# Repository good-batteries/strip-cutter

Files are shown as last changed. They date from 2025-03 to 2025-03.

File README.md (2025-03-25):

# Simple Strip Cutter

## Description

[Українська версія](README_ua.md)

Instructions on assembling a simple strip cutter used in battery manufacturing. The device also has the capability to weld a second layer of strip for welding copper using "sandwich" technology. Included are 3D print files and code for Arduino Nano.

- [Video introduction](https://www.youtube.com/watch?v=2g4eOFBQs-M)
- [Jig mentioned in the previous video](https://youtu.be/SqSB7JrVHbk)

Demo Gif

## Table of Contents

- [Arduino Nano Flashing](#arduino-nano-flashing)
- [List of Parts](#list-of-parts)
- [Electrical Schematic](#electrical-schematic)
- [TODO](#todo)

## Arduino Nano Flashing

- Install libraries using Arduino's IDE Library Manager:
  - Search for and install **AccelStepper**
  - Search for and install **VL53L0X_mod**
- If the welder functionality is not needed:
  - Change `bool needWelder = true;` to `bool needWelder = false;` in the code.
- To test modules separately, locate `// UNCOMMENT NEEDED TEST` in the code and follow the instructions provided.

## List of Parts

- **CNC Shield for Arduino Uno**  
  [https://vi.aliexpress.com/item/1005002807506440.html](https://vi.aliexpress.com/item/1005002807506440.html)
- **CNC Shield for Arduino Nano**  
  [https://vi.aliexpress.com/item/32834755847.html](https://vi.aliexpress.com/item/32834755847.html)
- **Step Motor NEMA17 JK42HS40**  
  [https://arduino.ua/prod2962-shagovii-dvigatel-nema17-jk42hs40-1704-13a-b](https://arduino.ua/prod2962-shagovii-dvigatel-nema17-jk42hs40-1704-13a-b)  
  [https://evse.com.ua/shagovyj-dvigatel-nema17-17a-17hs4401-3d-printer](https://evse.com.ua/shagovyj-dvigatel-nema17-17a-17hs4401-3d-printer)
- **Welding Handle**  
  [https://vi.aliexpress.com/item/1005006570618453.html](https://vi.aliexpress.com/item/1005006570618453.html)
- **Scissors JTC 3422A**  
  [https://jtc.com.ua/instrument-zagalnogo-priznachennya/instrument-slyusarnij/nozhici-bagatofunkcionalni/](https://jtc.com.ua/instrument-zagalnogo-priznachennya/instrument-slyusarnij/nozhici-bagatofunkcionalni/)
- **Relay 5V 10A Low Level**  
  [https://arduino.ua/prod1706-modyl-rele-5v-10a-nizkogo-yrovnya-low-level](https://arduino.ua/prod1706-modyl-rele-5v-10a-nizkogo-yrovnya-low-level)
- **Step Motor Driver StepStick A4988**  
  [https://arduino.ua/prod965-draiver-shagovogo-dvigatelya-stepstick-a4988](https://arduino.ua/prod965-draiver-shagovogo-dvigatelya-stepstick-a4988)
- **Laser Distance Sensor GY-530 on VL53L0X**  
  [https://arduino.ua/prod2144-lazernii-datchik-rasstoyaniya-gy-530-na-vl53l0x](https://arduino.ua/prod2144-lazernii-datchik-rasstoyaniya-gy-530-na-vl53l0x)
- **Strip**  
  [https://vi.aliexpress.com/item/1005008182375950.html](https://vi.aliexpress.com/item/1005008182375950.html)
- **Button**  
  [https://arduino.ua/prod3756-knopka-pbs-33b-bez-fiksacii-off-on-krasnaya](https://arduino.ua/prod3756-knopka-pbs-33b-bez-fiksacii-off-on-krasnaya)  
  [https://arduino.ua/prod3528-knopka-avariinoi-ostanovki](https://arduino.ua/prod3528-knopka-avariinoi-ostanovki)
- **Breadboard**  
  [https://arduino.ua/prod361-maketnaya-plata-mb-102-830-otverstii](https://arduino.ua/prod361-maketnaya-plata-mb-102-830-otverstii)
- **Breadboard for Soldering**  
  [https://arduino.ua/prod4130-mednaya-maketnaya-plata-diy-stripboard-iz-getinaksa-133x48-mm](https://arduino.ua/prod4130-mednaya-maketnaya-plata-diy-stripboard-iz-getinaksa-133x48-mm)
- **Arduino Nano**  
  [https://arduino.ua/prod6510-arduino-nano-v3-0-avr-atmega328p-type-c](https://arduino.ua/prod6510-arduino-nano-v3-0-avr-atmega328p-type-c)
- **Wires**  
  [https://arduino.ua/prod195-nabor-peremichek-dlya-arduino-65-sht](https://arduino.ua/prod195-nabor-peremichek-dlya-arduino-65-sht)
- **Voltage Regulator LM7805 TO-220**  
  [https://arduino.ua/prod1844-stabilizator-napryajeniya-lm7805-to-220](https://arduino.ua/prod1844-stabilizator-napryajeniya-lm7805-to-220)
- **Capacitor**  
  [https://arduino.ua/prod6477-kondensator-elektrolitichnii-jccon-47mkf-25v-lowesr](https://arduino.ua/prod6477-kondensator-elektrolitichnii-jccon-47mkf-25v-lowesr)
- **Resistors**  
  [https://arduino.ua/prod409-nabor-rezistorov-0-25w-600-sht](https://arduino.ua/prod409-nabor-rezistorov-0-25w-600-sht)
- **Servo SG90**  
  [https://arduino.ua/prod416-servoprivod-sg90-2kg](https://arduino.ua/prod416-servoprivod-sg90-2kg)
- **Plug 5.5x2.5mm**  
  [https://arduino.ua/prod1380-shteker-2-5-h-5-5-mm-papa-1-sht](https://arduino.ua/prod1380-shteker-2-5-h-5-5-mm-papa-1-sht)
- **Socket DC 5.5/2.5mm**  
  [https://arduino.ua/prod3909-gnezdo-pitaniya-dc-5-52-5mm-s-klemmnoi-kolodkoi-pod-vint](https://arduino.ua/prod3909-gnezdo-pitaniya-dc-5-52-5mm-s-klemmnoi-kolodkoi-pod-vint)
- **Power Supply 12V**  
  [https://evse.com.ua/blok-pitaniya-setevoj-adapter-12v-6a-55x21mm-55x25mm-kabel](https://evse.com.ua/blok-pitaniya-setevoj-adapter-12v-6a-55x21mm-55x25mm-kabel)

## Electrical Schematic

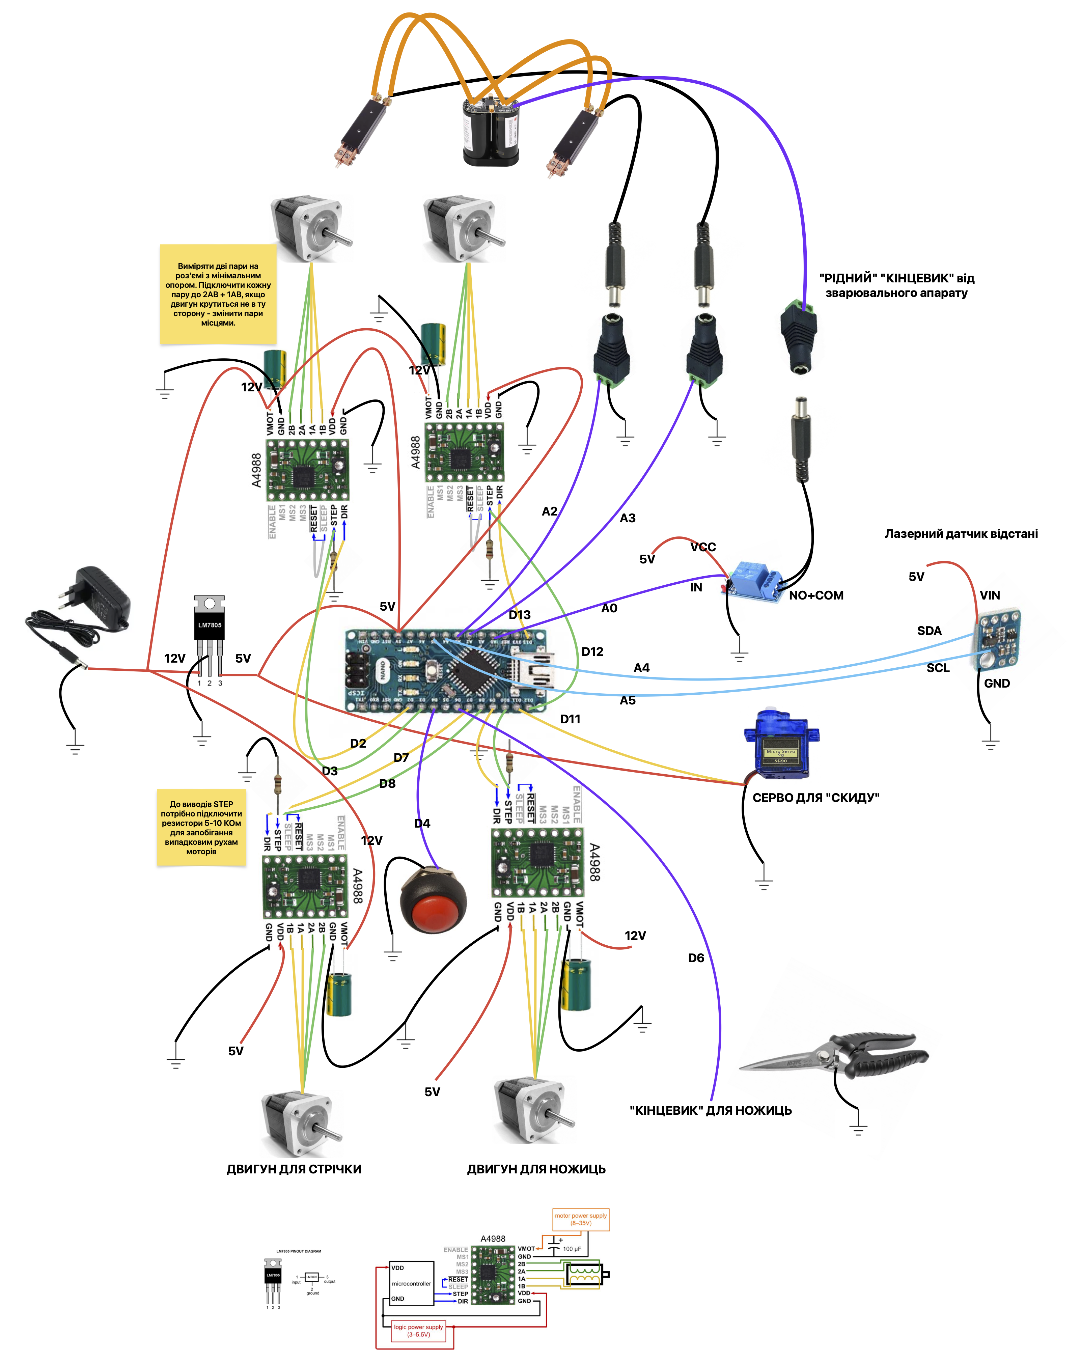
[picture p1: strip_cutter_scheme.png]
Strip Cutter Schematic


## TODO

- Clean up the code.
- Improve the electrical schematic.
- Redesign scissors motor holder - it is ugly.

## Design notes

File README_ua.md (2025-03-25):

# Простий Різак для Стрічки

## Опис

Інструкція зі складання простого різака для стрічки, який використовується у виробництві батарей. Пристрій також має можливість приварювати другий шар стрічки для зварювання міді за технологією "сендвіч". У комплекті є 3D-файли для друку та код для Arduino Nano.

- [Відео-інструкція](https://www.youtube.com/watch?v=2g4eOFBQs-M)
- [Кондуктор, згаданий у відео](https://youtu.be/SqSB7JrVHbk)

Demo Gif

## Зміст

- [Прошивка Arduino Nano](#прошивка-arduino-nano)
- [Список деталей](#список-деталей)
- [Електрична схема](#електрична-схема)
- [TODO](#todo)

## Прошивка Arduino Nano

- Встановіть бібліотеки за допомогою Менеджера бібліотек Arduino IDE:
  - Знайдіть та встановіть **AccelStepper**.
  - Знайдіть та встановіть **VL53L0X_mod**.
- Якщо функція зварювання не потрібна:
  - Змініть `bool needWelder = true;` на `bool needWelder = false;` у коді.
- Для тестування модулів окремо знайдіть `// UNCOMMENT NEEDED TEST` у коді та дотримуйтеся інструкцій.

## Список деталей

- **CNC Shield для Arduino Uno**  
  [https://vi.aliexpress.com/item/1005002807506440.html](https://vi.aliexpress.com/item/1005002807506440.html)
- **CNC Shield для Arduino Nano**  
  [https://vi.aliexpress.com/item/32834755847.html](https://vi.aliexpress.com/item/32834755847.html)
- **Кроковий двигун NEMA17 JK42HS40**  
  [https://arduino.ua/prod2962-shagovii-dvigatel-nema17-jk42hs40-1704-13a-b](https://arduino.ua/prod2962-shagovii-dvigatel-nema17-jk42hs40-1704-13a-b)  
  [https://evse.com.ua/shagovyj-dvigatel-nema17-17a-17hs4401-3d-printer](https://evse.com.ua/shagovyj-dvigatel-nema17-17a-17hs4401-3d-printer)
- **Зварювальний тримач**  
  [https://vi.aliexpress.com/item/1005006570618453.html](https://vi.aliexpress.com/item/1005006570618453.html)
- **Ножиці JTC 3422A**  
  [https://jtc.com.ua/instrument-zagalnogo-priznachennya/instrument-slyusarnij/nozhici-bagatofunkcionalni/](https://jtc.com.ua/instrument-zagalnogo-priznachennya/instrument-slyusarnij/nozhici-bagatofunkcionalni/)
- **Реле 5V 10A (низький рівень)**  
  [https://arduino.ua/prod1706-modyl-rele-5v-10a-nizkogo-yrovnya-low-level](https://arduino.ua/prod1706-modyl-rele-5v-10a-nizkogo-yrovnya-low-level)
- **Драйвер крокового двигуна StepStick A4988**  
  [https://arduino.ua/prod965-draiver-shagovogo-dvigatelya-stepstick-a4988](https://arduino.ua/prod965-draiver-shagovogo-dvigatelya-stepstick-a4988)
- **Лазерний датчик відстані GY-530 на VL53L0X**  
  [https://arduino.ua/prod2144-lazernii-datchik-rasstoyaniya-gy-530-na-vl53l0x](https://arduino.ua/prod2144-lazernii-datchik-rasstoyaniya-gy-530-na-vl53l0x)
- **Стрічка**  
  [https://vi.aliexpress.com/item/1005008182375950.html](https://vi.aliexpress.com/item/1005008182375950.html)
- **Кнопка**  
  [https://arduino.ua/prod3756-knopka-pbs-33b-bez-fiksacii-off-on-krasnaya](https://arduino.ua/prod3756-knopka-pbs-33b-bez-fiksacii-off-on-krasnaya)  
  [https://arduino.ua/prod3528-knopka-avariinoi-ostanovki](https://arduino.ua/prod3528-knopka-avariinoi-ostanovki)
- **Макетна плата**  
  [https://arduino.ua/prod361-maketnaya-plata-mb-102-830-otverstii](https://arduino.ua/prod361-maketnaya-plata-mb-102-830-otverstii)
- **Перфорована плата для паяння**  
  [https://arduino.ua/prod4130-mednaya-maketnaya-plata-diy-stripboard-iz-getinaksa-133x48-mm](https://arduino.ua/prod4130-mednaya-maketnaya-plata-diy-stripboard-iz-getinaksa-133x48-mm)
- **Arduino Nano**  
  [https://arduino.ua/prod6510-arduino-nano-v3-0-avr-atmega328p-type-c](https://arduino.ua/prod6510-arduino-nano-v3-0-avr-atmega328p-type-c)
- **Дроти**  
  [https://arduino.ua/prod195-nabor-peremichek-dlya-arduino-65-sht](https://arduino.ua/prod195-nabor-peremichek-dlya-arduino-65-sht)
- **Стабілізатор напруги LM7805 TO-220**  
  [https://arduino.ua/prod1844-stabilizator-napryajeniya-lm7805-to-220](https://arduino.ua/prod1844-stabilizator-napryajeniya-lm7805-to-220)
- **Конденсатор**  
  [https://arduino.ua/prod6477-kondensator-elektrolitichnii-jccon-47mkf-25v-lowesr](https://arduino.ua/prod6477-kondensator-elektrolitichnii-jccon-47mkf-25v-lowesr)
- **Резистори**  
  [https://arduino.ua/prod409-nabor-rezistorov-0-25w-600-sht](https://arduino.ua/prod409-nabor-rezistorov-0-25w-600-sht)
- **Серво SG90**  
  [https://arduino.ua/prod416-servoprivod-sg90-2kg](https://arduino.ua/prod416-servoprivod-sg90-2kg)

## Електрична схема

Схема різака стрічки

## TODO

- Оптимізувати код.
- Покращити електричну схему.
- Переробити дизайн для двигуна ножиць, він зараз уродливий.

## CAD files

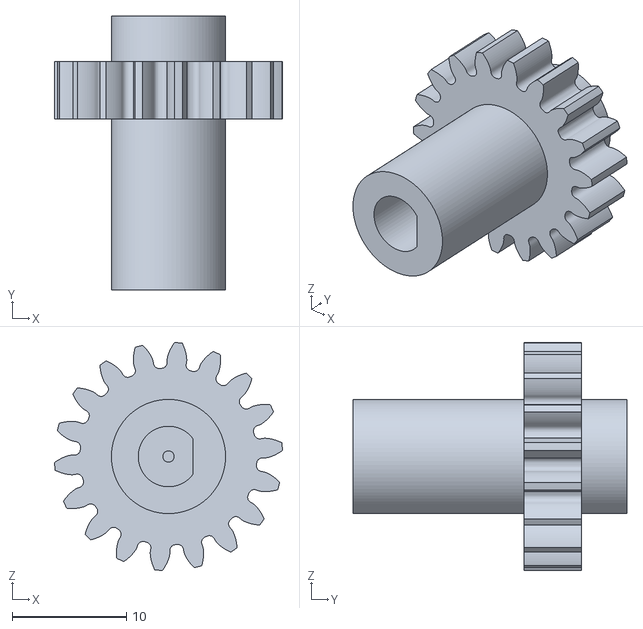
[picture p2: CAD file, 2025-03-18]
3D Print/Welder Mover/MainGear.stl
20.0 x 24.0 x 20.0

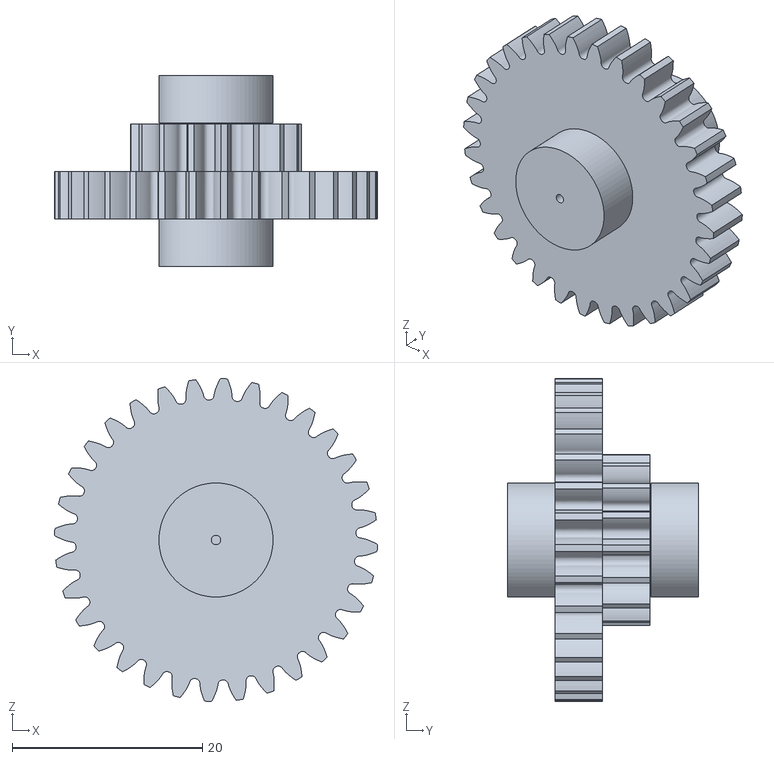
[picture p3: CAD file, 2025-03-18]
3D Print/Strip Mover/MainGears.stl
34.0 x 20.1 x 34.0

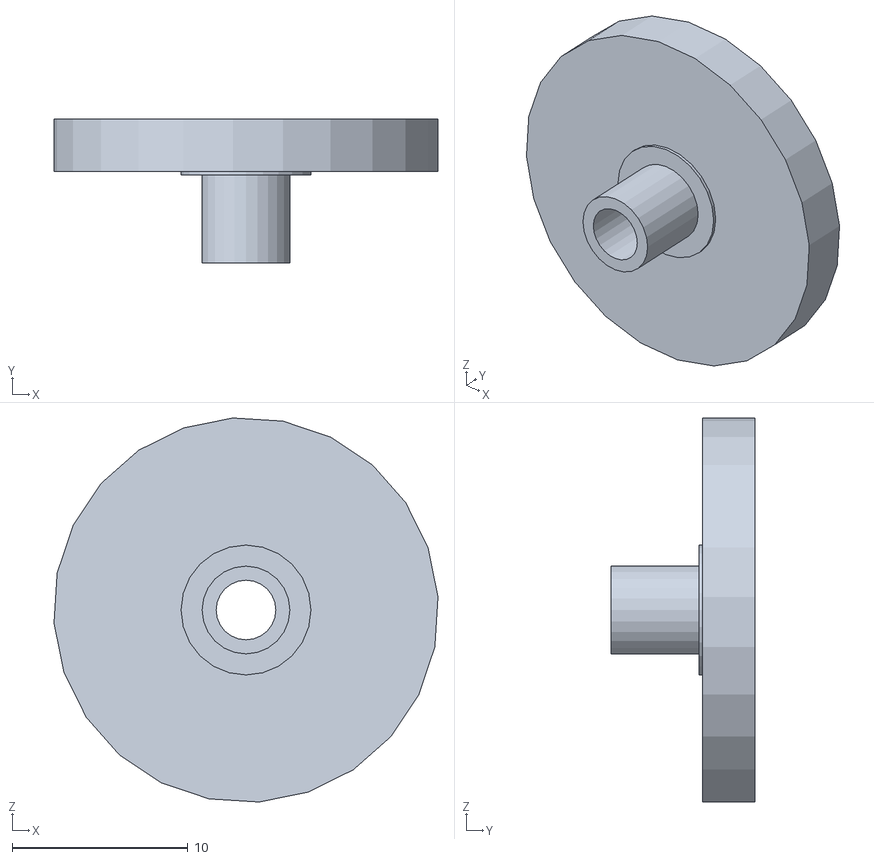
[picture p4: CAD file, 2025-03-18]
3D Print/Scissors Mover/Bearing_Holder.stl
21.9 x 8.20 x 21.9

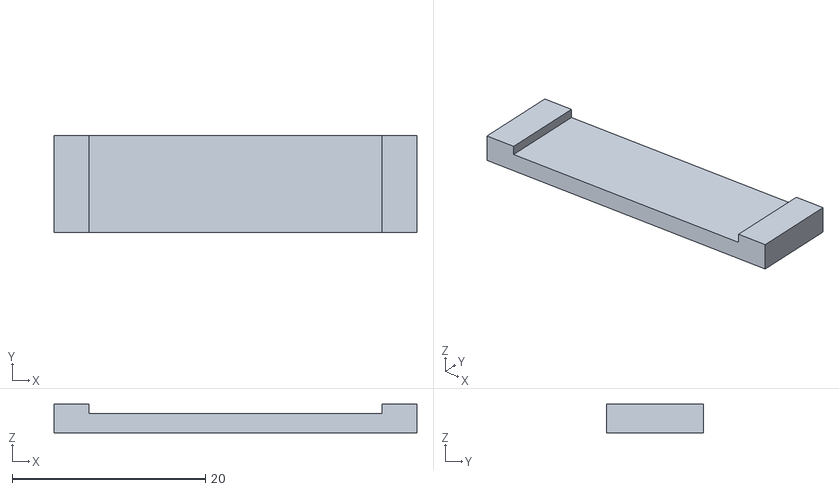
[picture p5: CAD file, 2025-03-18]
3D Print/Strip Guide/Double Sandwich/cap1.stl
37.6 x 10.0 x 3.00

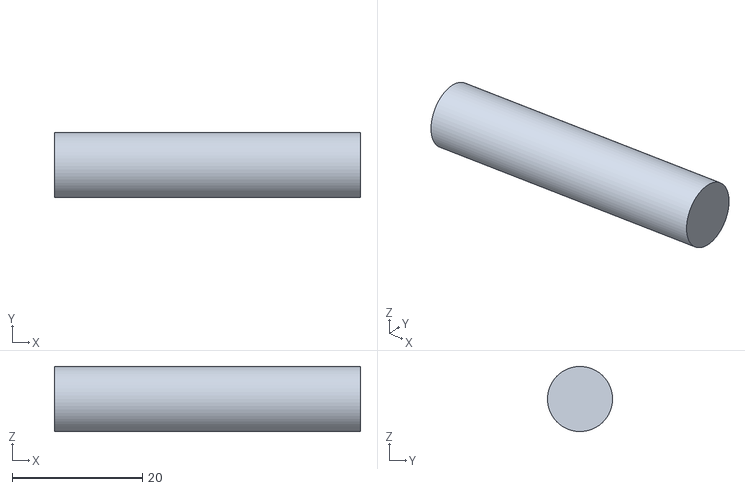
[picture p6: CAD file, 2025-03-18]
3D Print/Strip Guide/Pin.stl
47.0 x 9.99 x 10.00

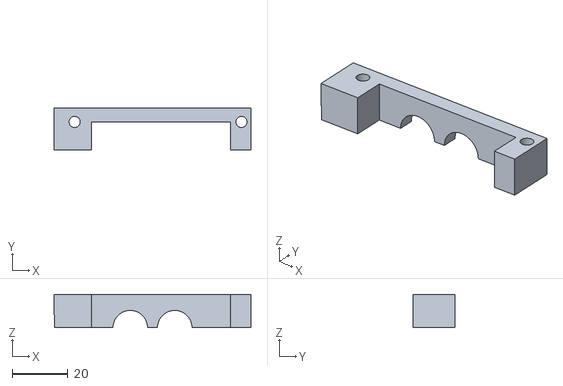
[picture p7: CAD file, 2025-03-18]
3D Print/Strip Mover/Frame1_Top.stl
70.9 x 15.1 x 12.0

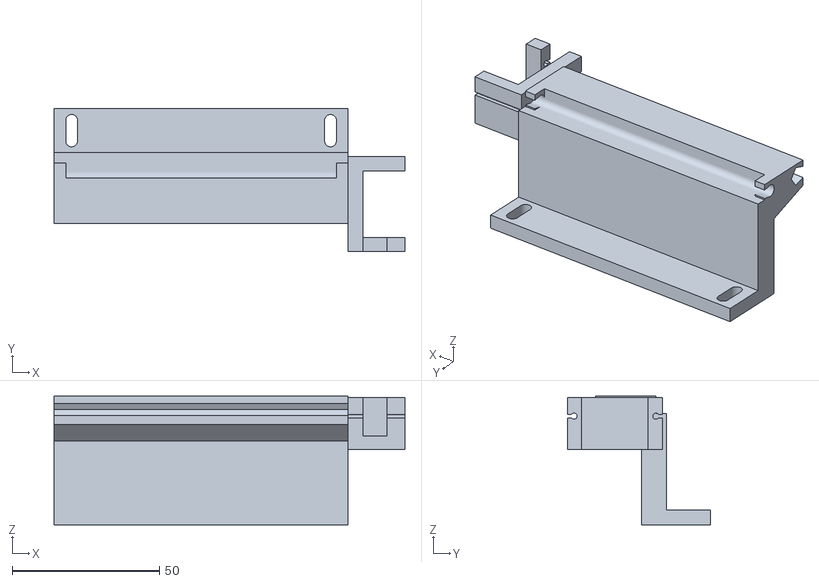
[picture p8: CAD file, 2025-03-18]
3D Print/Strip Sensor Support/Sensor Stand.stl
119.3 x 48.5 x 43.7

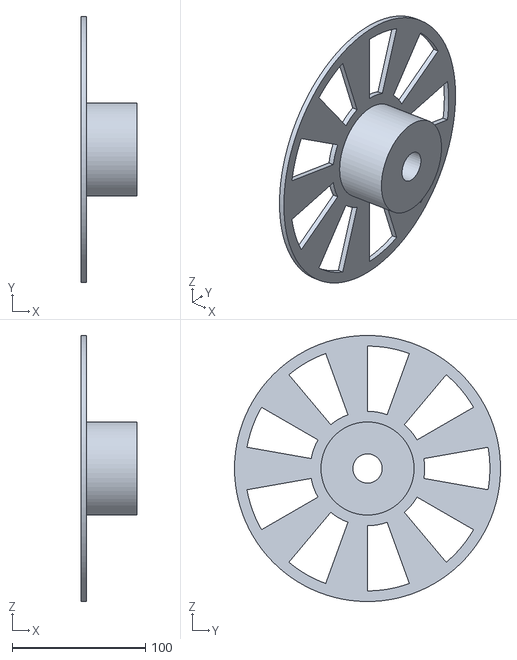
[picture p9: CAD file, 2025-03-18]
3D Print/Strip Spool/BaseCircle.stl
42.0 x 200.0 x 200.0

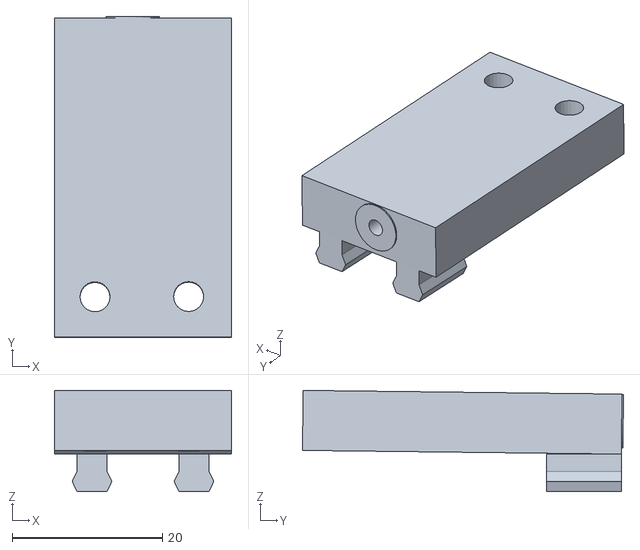
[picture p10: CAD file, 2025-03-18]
3D Print/Scissors Mover/Bearing_Holder_Frame_bottom.stl
23.6 x 42.8 x 13.5

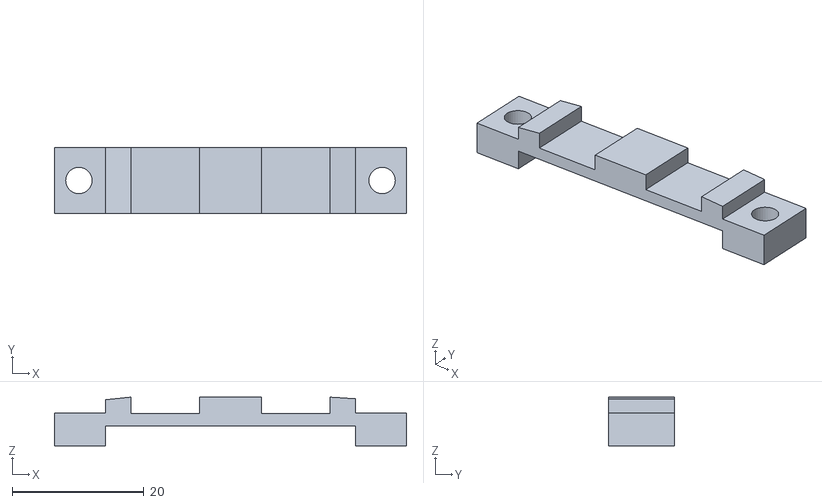
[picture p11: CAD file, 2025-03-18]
3D Print/Strip Guide/Double Sandwich/cap2.stl
53.4 x 10.0 x 7.40

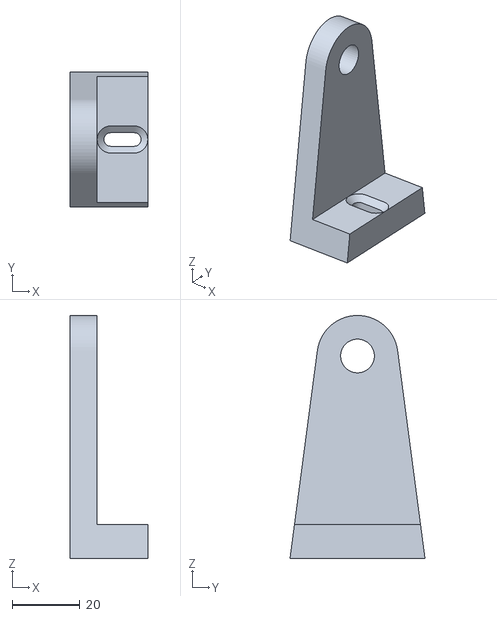
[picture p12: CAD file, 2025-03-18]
3D Print/Strip Guide/Frame.stl
23.0 x 40.0 x 72.0

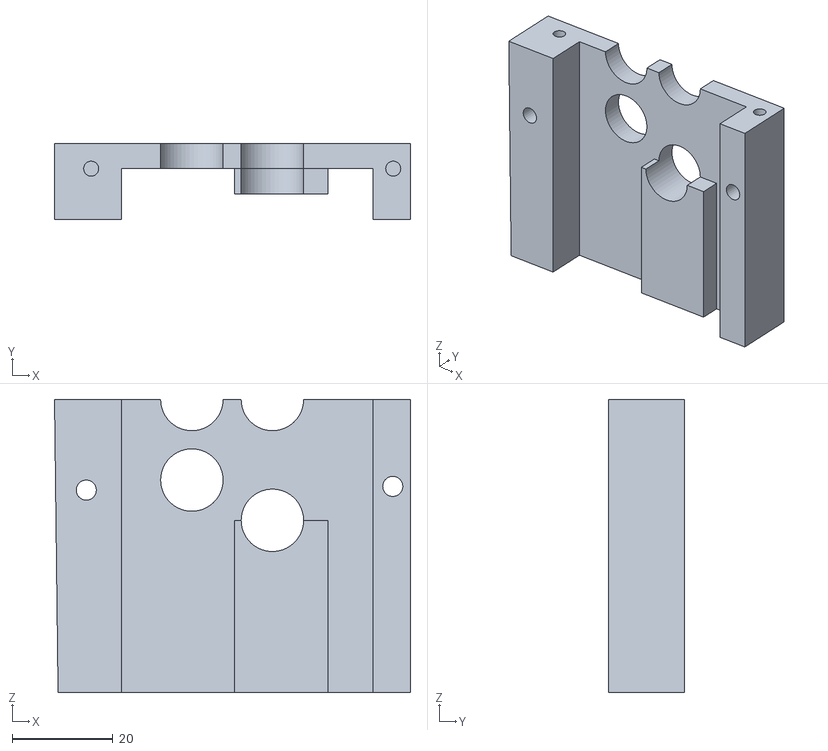
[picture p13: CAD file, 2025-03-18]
3D Print/Strip Mover/Frame1_Bottom.stl
70.7 x 15.1 x 58.2

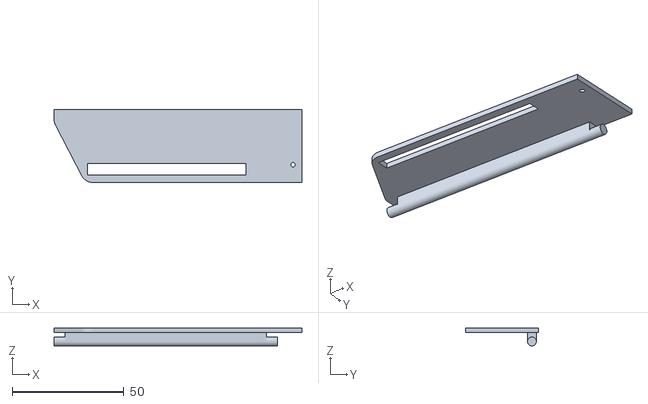
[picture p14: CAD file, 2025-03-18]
3D Print/Strip Sensor Support/Flipper.stl
111.0 x 32.8 x 7.99

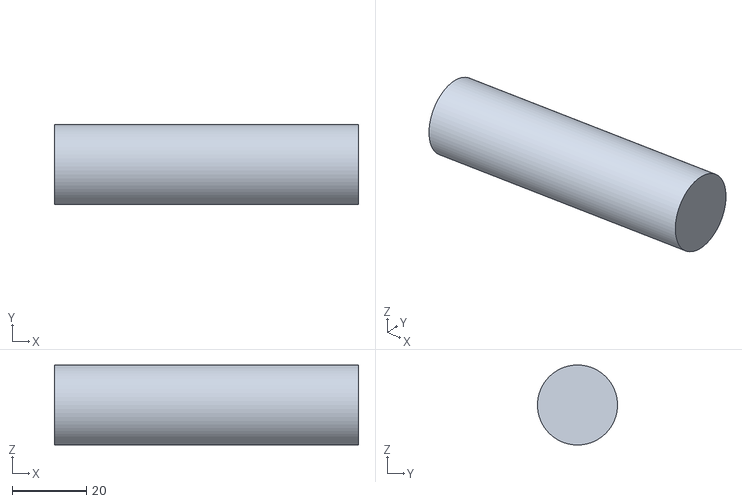
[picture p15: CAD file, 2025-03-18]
3D Print/Strip Spool/CenterPin.stl
82.0 x 21.6 x 21.6

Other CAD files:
3D Print/Welder Mover/BigGear.stl
3D Print/Scissors Mover/Bottom.stl
3D Print/Strip Guide/Double Sandwich/cap3.stl
3D Print/Strip Mover/Spindel1.stl
3D Print/Scissors Mover/Bearing_Holder_Frame.stl
3D Print/Scissors Mover/Bearing_Holder_Frame_top.stl
3D Print/Scissors Mover/Scissors Holder.f3d
3D Print/Scissors Mover/Scissors Holder.stl
3D Print/Scissors Mover/ScissorsRopeCap.stl
3D Print/Scissors Mover/ServoFrame.stl
3D Print/Strip Mover/DriveGear.stl
3D Print/Strip Mover/Frame2.stl
3D Print/Strip Mover/OpossiteSupport.stl
3D Print/Strip Mover/Strip Mover.f3z
3D Print/Strip Sensor Support/SensorHolder.stl
3D Print/Strip Sensor Support/Strip Sensor Support.f3d
3D Print/Strip Spool/BaseCircle_10mm.stl
3D Print/Strip Spool/CenterPin_10mm.stl
3D Print/Strip Spool/OuterCircle.stl
3D Print/Strip Spool/Spacer.stl
3D Print/Strip Spool/Spacer_98.stl
3D Print/Strip Spool/Stand.stl
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

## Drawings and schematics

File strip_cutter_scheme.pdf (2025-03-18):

## "РІДНИЙ" "КІНЦЕВИК" від зварювального апарату

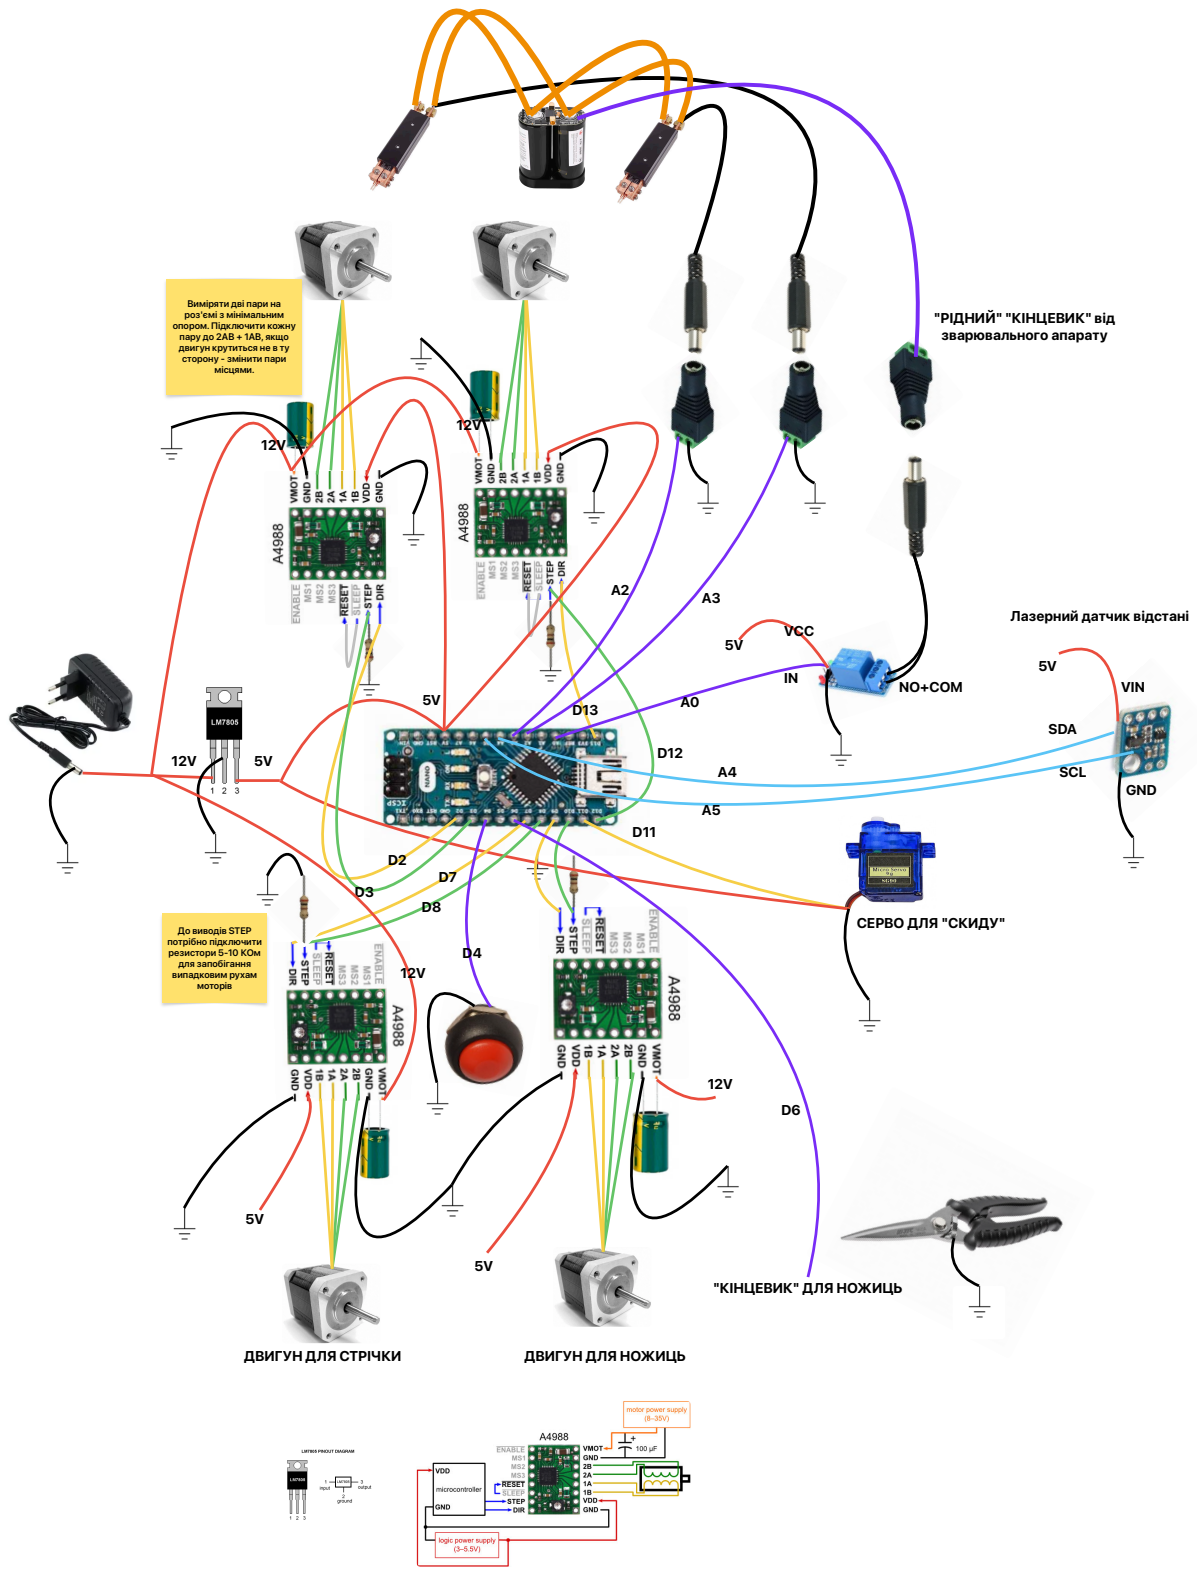
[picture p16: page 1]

Виміряти дві пари на
роз'ємі з мінімальним
опором. Підключити кожну
пару до 2AB + 1AB, якщо
двигун крутиться не в ту
сторону - змінити пари
місцями.

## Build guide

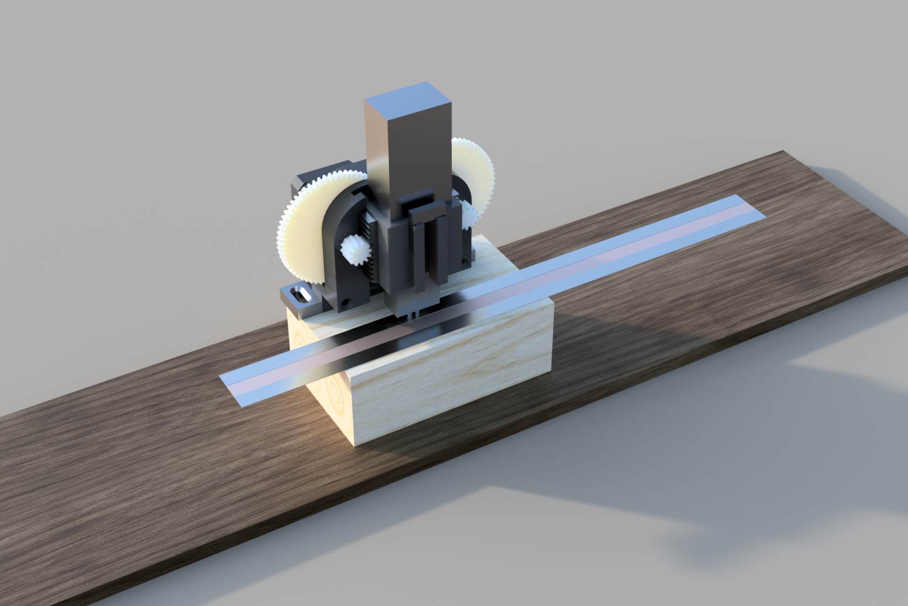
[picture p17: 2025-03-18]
3D Print/Welder Mover/Weld Mover v6.png

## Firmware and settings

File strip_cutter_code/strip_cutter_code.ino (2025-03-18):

#include <AccelStepper.h>
//#include "Adafruit_VL53L0X.h" // Too much memory and too slow
#include "VL53L0X_mod.h"
#include <Servo.h>
VL53L0X_mod lox;
// default pins for SDA - A4, SCL - A5

#define motorInterfaceType 1

#define welderDirPin 2 //d2
#define welderStepPin 3 //d3
AccelStepper welderStepper = AccelStepper(motorInterfaceType, welderStepPin, welderDirPin);

#define welder2DirPin 13 // d13
#define welder2StepPin 12 //d12
AccelStepper welder2Stepper = AccelStepper(motorInterfaceType, welder2StepPin, welder2DirPin);

#define stripDirPin 7
#define stripStepPin 8
AccelStepper stripStepper = AccelStepper(motorInterfaceType, stripStepPin, stripDirPin);

#define scissorsDirPin 9
#define scissorsStepPin 10
AccelStepper scissorsStepper = AccelStepper(motorInterfaceType, scissorsStepPin, scissorsDirPin);

#define buttomPin 4 // D4 (other end is GND)
#define stripSensorPin 5 // D5 (other end is GND)
#define scissorsPin 6 // D6 (other end is GND)

#define welderPressPin A2 // (other end is GND)
#define welderPressPin2 A3 // (other end is GND)
#define welderOutputPin A0 
#define welderOutputPin2 A1 


// OTHER
bool forwardDir = false;
bool btnWasPressed = false;

unsigned long lastDebounceTime = 0;  // the last time the output pin was toggled
unsigned long debounceDelay = 50; 
int lastButtonState = LOW;

// Strip

// set false for stepsMode, if you need to cut preciselly at stop sensor.
// otherwise, strip length will be based on the step motor steps count - not very precise in this implementation.
// and sensor will be used as a strip jamming/running out/slippage sensor. Hence put the sensor BEFORE the needed steps count
// make sure there is no strip slippage to have precise cutting, otherwise use sensor based mode 
bool stepsMode = false;
// used only if stepsMode = true. Adjust for needed strip length. Approximatelly 10mm = 68 steps

long expectedStepsPerStrip = 500; 

// lower speed -> more precise and more torque
int stripSpeed = 900;
int throttledSpeed = 100;
float startThrottleAt = 0.85;


unsigned long stepsWhenStripStopped = 0;
long stepsPerStrip = 0; // measured
bool stripSensorTriggered = false;


const int StripStateMoving = 1;
const int StripStateWaiting = 3;
int stripState = StripStateWaiting;

// Flipper
#define servoPin 11 // D11
Servo Servo1;
// 90grad is full release.
// 0 is locked
int closed_deg = 45;
int open_deg = 230; // go slightly further to be sure

long openTimeMs = 300;
long closingTimeMs = 300;

long openTimeStartedMs = 0;
long closingTimeStartedMs = 0;

bool needFlipper = true; // false is not implemented. If not needed - then just not connect and reduce duration to minimum needed

const int FlipperStateReady = 0;
const int FlipperStateWaiting = 3;
const int FlipperStateOpening = 2;
const int FlipperStateClosing = 1;

int flipperState = FlipperStateWaiting;

// Welder
bool needWelder = true; // set false - if welding is not needed

int welderSpeed = 1200;
int stepsToWelderStepBack = 330;
int weldDelay = 50;
long weldWaitingDelay = 100;

const int WelderStateReady = 4;
const int WelderStatePauseBeforeMoving = 6;
const int WelderStateMoving = 1;
const int WelderStateWaitingSpotWeld = 5;
const int WelderStateBackingBack = 2;
const int WelderStateWaiting = 3;


long  welderTriggerDurationMs = 50;

const int WelderTriggerStateWaiting = 1;
const int WelderTriggerStateActivated = 2;
const int WelderTriggerStateDone = 3;

int welderTriggerState = WelderTriggerStateWaiting;

int welderState[2] = {WelderStateWaiting, WelderStateWaiting};
long welderWaitingMs[2] = {0, 0};

long stepsWhenWelderStopped[2] = {0,0};
unsigned long weldWaitStartTimeDelay[2] = {0,0};


// Scissors
int scissorsSpeed = 1100;
int scissorsBackSpeed = 1200;
int stepsToScissorsStepBack = 700; // CHANGE THIS TO ADJUST HOW FAR SCISSORS SHOULD STEP BACK AFTER CUT

const int ScissorsStateMoving = 1;
const int ScissorsStateBackingBack = 2;
const int ScissorsStateWaiting = 3;
const int ScissorsStateReady = 4;
int scissorsState = ScissorsStateWaiting;
int stepsWhenScissorsStopped = 0;


void setup() {
  Serial.begin(115000);
  Serial.println(F("Start Init"));

  pinMode(welderPressPin, INPUT_PULLUP);
  pinMode(welderPressPin2, INPUT_PULLUP);
  
  pinMode(welderOutputPin, OUTPUT);
  pinMode(welderOutputPin2, OUTPUT);
  digitalWrite(welderOutputPin, HIGH); // turn off relay by default
  digitalWrite(welderOutputPin2, HIGH); //

  pinMode(buttomPin, INPUT_PULLUP);
  pinMode(stripSensorPin, INPUT_PULLUP);
  pinMode(scissorsPin, INPUT_PULLUP);

  Servo1.attach(servoPin, 500,2500);
  Servo1.write(closed_deg); 
  Serial.println(F("Servo init done"));

  lox.init();
  lox.setTimeout(500);
  lox.startContinuous();
  Serial.println(F("Lox init done"));

  stripStepper.setMaxSpeed(10000);
  welderStepper.setMaxSpeed(2600);
  welder2Stepper.setMaxSpeed(2600);
  scissorsStepper.setMaxSpeed(2600);

  Serial.println(F("Init Completed"));
}


bool iteractionAllowed = false;
bool hasError = false;
unsigned long buttonPressedMillis = 0;

unsigned long changeModeBtnDelay = 1000;
bool samePress = false;
bool modeDidChange = false;

#define MODE_NORMAL 0
#define MODE_STRIP_TEST 1
#define MODE_WELD_TEST 2
#define MODES_COUNT 3

int currentMode = 0;


unsigned long prevSpeed;
unsigned long previousBeepMillis = 0;
unsigned long beepIntervalMs = 300;
unsigned long beepFreq = 4000;
bool isBeep = false;



void doError() {
  prevSpeed = stripStepper.speed(); // save prev speed, as we will be overriding it for beep signal.
  hasError = true;
  iteractionAllowed = false;
}

void clearError() {
  stripStepper.setSpeed(prevSpeed);
  hasError = false;
}


void loop() {
  int btnVal = digitalRead(buttomPin);
  if (btnVal != lastButtonState) {
    // reset the debouncing timer
    lastDebounceTime = millis();
  }
  lastButtonState = btnVal;

  if ((millis() - lastDebounceTime) > debounceDelay) {
    // we are ready to read button state

    if (!btnVal) {
      // Button currenlty pressed      

      if (!btnWasPressed) {
        // fired once after button is pressed
        Serial.println("BUTTON PRESSED");

        buttonPressedMillis = millis();
        modeDidChange = false;
        if (iteractionAllowed) {
          iteractionAllowed = false;
          samePress = true;
          Serial.println("STOPPED");
        }
        btnWasPressed = true;
      }

      // Long press - mode change
      if ((millis() - buttonPressedMillis) > changeModeBtnDelay) {
        // if pressed for some time - it is mode change
        buttonPressedMillis = millis();
        modeDidChange = true;
        currentMode = ((currentMode + 1) % MODES_COUNT);
        Serial.println("MODE CHANGED: " + String (currentMode));
        // mode mode change sound
        for (int i = 0; i < (currentMode+1); i++) {
          makeBeep();
          delay(300);
        }
        delay(1000);
      }
    } else {
      // Button currenlty released      

      buttonPressedMillis = 0;

      if (btnWasPressed) {
        // fired once after button is pressed
        Serial.println("BUTTON RELEASED");

        if (!modeDidChange) {
          // Just start/resume
          if (!iteractionAllowed && !samePress) {
            if (hasError) {
              clearError();
            }
            iteractionAllowed = true;
            Serial.println("STARTED");
          }
        }
        btnWasPressed = false;
        samePress = false;
      }
    }



  }

  if (hasError) {
    unsigned long currentMillis = millis();
    if (currentMillis - previousBeepMillis >= beepIntervalMs) {
        previousBeepMillis = currentMillis;
        if (isBeep) {
          stripStepper.setSpeed(beepFreq);
        } else {
          stripStepper.setSpeed(0);
        }
        isBeep = !isBeep;
    }
    stripStepper.runSpeed();
  }


  if (iteractionAllowed == false) {
    return;    
  }



// UNCOMMENT NEEDED TEST
// testWelder();
// testWelder2();  
// testScissors();
// testFlipper();  
// testStripStopper();
// testBothWelders();
// AND COMMENT FROM HERE >>>
  switch (currentMode) {
    case MODE_NORMAL:
    masterLoop(); 
    break;
    case MODE_STRIP_TEST:
    testStripStopper(); // Could be used for initial length calibration without cutting strip
    break;
    case MODE_WELD_TEST:
    testBothWelders(); // Could be used for initial welding 
    break;
  }
// TO HERE <<<


  stripStepper.runSpeed();
  welderStepper.runSpeed();
  welder2Stepper.runSpeed();
  scissorsStepper.runSpeed();
}

void testStripStopper() {
  if (welderState[0] == WelderStateReady) {
    welderState[0] = WelderStateWaiting;
    scissorsState = WelderStateWaiting;
    stripState = StripStateWaiting;
    scissorsState = ScissorsStateWaiting;
    flipperState = FlipperStateWaiting;

    iteractionAllowed = false;
    return;
    
    Serial.println("testStripStopper Start");
  }
  doStripMoving();
}


void testFlipper() {
  if (flipperState == FlipperStateWaiting) {
    flipperState = FlipperStateReady;
    Serial.println("testFlipper Start");
    iteractionAllowed = false;
    return;
  }
  doFlip();  
}


void testWelder() {
  if (welderState[0] == WelderStateWaiting) {
    stripState = StripStateWaiting;
    welderState[0] = WelderStateReady;
    Serial.println("testWelder Start");
  }
  doWelder(0, &welderStepper, &welder2Stepper);

  welderState[1] =  WelderStateWaitingSpotWeld;
  doWelderTrigger();
}


void testWelder2() {
  if (welderState[1] == WelderStateWaiting) {
    stripState = StripStateWaiting;
    welderState[1] = WelderStateReady;
    Serial.println("testWelder2 Start");
  }
  doWelder(1, &welderStepper, &welder2Stepper);

  welderState[0] =  WelderStateWaitingSpotWeld;
  doWelderTrigger();
}


void testBothWelders() {
  if (welderState[0] == WelderStateWaiting && welderState[1] == WelderStateWaiting) {
    stripState = StripStateWaiting;
    welderState[0] = WelderStateReady;
    iteractionAllowed = false;
    return;
  }

  doWelder(0, &welderStepper, &welder2Stepper);
  doWelder(1, &welderStepper, &welder2Stepper);
  doWelderTrigger();
}


void testScissors() {
  if (scissorsState == ScissorsStateWaiting) {
    scissorsState = ScissorsStateReady;
    Serial.println("testScissors Start");
  }
  doScissors();
}


void doStripMoving() {
  // ----------------  StripStateMoving --------------------
  if (stripState == StripStateWaiting && (!needWelder || (welderState[0] == WelderStateWaiting && welderState[1] == WelderStateWaiting)) && scissorsState == ScissorsStateWaiting && (!needFlipper || flipperState == FlipperStateWaiting)) {
    stripState = StripStateMoving;
    stripStepper.setSpeed(stripSpeed);
    Serial.println("STRIP STARTED MOVING");
    stripSensorTriggered = false;
  }
 
  if (stripState == StripStateMoving) {

    if (!stepsMode) {
      // Strip throttling at the end to have better precision
      unsigned long startAtPos = stepsWhenStripStopped + stepsPerStrip * startThrottleAt;
      unsigned long endAtPos = stepsWhenStripStopped + stepsPerStrip * 1.0;
      unsigned long lenSteps = endAtPos - startAtPos;
      
      if (stepsPerStrip == 0) {
        if (stripStepper.speed() != throttledSpeed) {
          stripStepper.setSpeed(throttledSpeed);
          Serial.println("INITIAL STRIP THROTTLE");    
        }
      }
      else if (stripStepper.currentPosition() >= startAtPos) {
        unsigned long finalSpeed = throttledSpeed;
        if (stripStepper.speed() != finalSpeed) {
          stripStepper.setSpeed(finalSpeed);
          // Serial.println("STRIP THROTTLED. finalSpeed: " +  String(finalSpeed)+ "; Pos: " + String(stripStepper.currentPosition()));    
        }
      }

      // check strip overflow
      if (stepsPerStrip != 0 && stripStepper.currentPosition()  >= (stepsWhenStripStopped + stepsPerStrip * 1.5)) {
        stepsPerStrip = 0;
        Serial.println("ERROR: STRIP OVERFLOW");    
        doError();
        return;
      }
    }
    
    uint16_t distance;
    if (lox.readRangeNoBlocking(distance)) {
        if (distance != 65535 && distance != 0) { // 65535 indicates a timeout
            // Do not log anythig if not necessity as it disrupts the motor movements
            //  Serial.print("Distance (mm): ");
            //  Serial.println(distance);
            if (distance < 60) {
              stripSensorTriggered = true;
            }
        } else {
            Serial.println("Error occurred");
        }
    }

    bool readyToCut = false;
    if (stepsMode) {
      if (stripStepper.currentPosition()  >= stepsWhenStripStopped + expectedStepsPerStrip ) {
        if (stripSensorTriggered) {
          // sensor should be triggered at this point - otherwise strip is stuck etc...
          readyToCut = true;
        } else {
          Serial.println("ERROR: SENSOR NOT TRIGGERED BEFORE CUT");    
          doError();
          return;
        }
      }
    } else {
      readyToCut = stripSensorTriggered;
    }
    


    if (readyToCut) {
      stepsPerStrip = stripStepper.currentPosition() - stepsWhenStripStopped;
      stepsWhenStripStopped = stripStepper.currentPosition();
      stripStepper.setSpeed(0);
      Serial.println("STRIP STOPPED. Pos: " + String(stripStepper.currentPosition()) + " stepsPerStrip : " + String(stepsPerStrip)  + " at speed: " + String(stripStepper.speed()) );     

      stripState = StripStateWaiting;
      if (needWelder) {
        welderState[0] = WelderStateReady;
    //      welderState[1] = WelderStateReady;
      }
      scissorsState = ScissorsStateReady;
    }
  }
}
  

void doScissors() {
  // ----------------  SCISSORS --------------------
  if (stripState == StripStateWaiting && scissorsState == ScissorsStateReady /* && (welderState[1] == WelderStateBackingBack || welderState[1] == WelderStateWaiting)*/) {
      scissorsStepper.setSpeed(scissorsSpeed);
      scissorsState = ScissorsStateMoving;
      Serial.println("SCISSORS STATED MOVING" + String(scissorsStepper.currentPosition()));
  }
  if (scissorsState == ScissorsStateMoving) {
    int scissorsSensVal = digitalRead(scissorsPin);
    if (!scissorsSensVal) {
      Serial.println("scissors STOPPED MOVING " + String(scissorsStepper.currentPosition()));
      scissorsState = ScissorsStateBackingBack;
      scissorsStepper.setSpeed(-scissorsBackSpeed);
      stepsWhenScissorsStopped = scissorsStepper.currentPosition();
    }
  }
  if (scissorsState == ScissorsStateBackingBack) {
    if (scissorsStepper.currentPosition() < stepsWhenScissorsStopped - stepsToScissorsStepBack) {
      scissorsStepper.setSpeed(0);
      scissorsState = ScissorsStateWaiting;
      if (needFlipper) {
        flipperState = FlipperStateReady;
      }
      Serial.println("scissors STOPPED BACKING BACK" + String(scissorsStepper.currentPosition()));
    }
  }  
}

// ----------------  FLIPPER --------------------
void doFlip() {
  if (flipperState == FlipperStateReady) {
    openTimeStartedMs = millis();
    flipperState = FlipperStateOpening;
  }

  if (flipperState == FlipperStateOpening) {
    Servo1.write(open_deg); 
    if (millis() - openTimeStartedMs > openTimeMs) {
      closingTimeStartedMs = millis();
      flipperState = FlipperStateClosing;
    }
  }

  if (flipperState == FlipperStateClosing) {
    Servo1.write(closed_deg); 
    if (millis() - closingTimeStartedMs > closingTimeMs) {
      flipperState = FlipperStateWaiting;
      
    }
  } 
}


void masterLoop() {
  doStripMoving();
  if (needWelder) {
    doWelder(0, &welderStepper, &welder2Stepper);
    doWelder(1, &welderStepper, &welder2Stepper);
    doWelderTrigger();
  }
  doScissors();
  doFlip();
}


unsigned long welderTriggerStartedMs = 0;
void doWelderTrigger() {
  if (welderTriggerState == WelderTriggerStateWaiting && (welderState[0] == WelderStateWaitingSpotWeld || welderState[1] == WelderStateWaitingSpotWeld)) {
    welderTriggerStartedMs = millis();
    welderTriggerState = WelderTriggerStateActivated;
    digitalWrite(welderOutputPin, LOW); 
    digitalWrite(welderOutputPin2, LOW);
    Serial.println("WELDER TRIGGER ACTIVATED");
  }

  if (welderTriggerState == WelderTriggerStateActivated) {
    if (millis() - welderTriggerStartedMs > welderTriggerDurationMs) {
        welderTriggerState = WelderTriggerStateDone;
        digitalWrite(welderOutputPin, HIGH); 
        digitalWrite(welderOutputPin2, HIGH);
        Serial.println("WELDER TRIGGER DONE");
    }
  }
}

void doWelder(int welderIndex, AccelStepper* welder0Stepper, AccelStepper* welder1Stepper) {
  AccelStepper* welderStepper;
  bool welderPressed = false;
  bool needPauseBeforeMoving = false;
  if (welderIndex == 0) {
    welderStepper = welder0Stepper;
    welderPressed = !digitalRead(welderPressPin);
//    digitalWrite(welderOutputPin, welderPressed); 
  }
  if (welderIndex == 1) {
    welderStepper = welder1Stepper;
    welderPressed = !digitalRead(welderPressPin2);
//   digitalWrite(welderOutputPin2, welderPressed);
//    needPauseBeforeMoving = true;
  }
  
  // Welder  
  if (stripState == StripStateWaiting && welderState[welderIndex] == WelderStateReady) {
      if (needPauseBeforeMoving) {
        welderState[welderIndex] = WelderStatePauseBeforeMoving;
        welderWaitingMs[welderIndex] = millis();
      } else {
        welderState[welderIndex] = WelderStateMoving;
        welderStepper->setSpeed(welderSpeed);
        Serial.println("WELDER STATED MOVING" + String(welderStepper->currentPosition()));
      }
  }
  if (welderState[welderIndex] == WelderStatePauseBeforeMoving) {
    if (millis() - welderWaitingMs[welderIndex] > weldWaitingDelay) {
        welderState[welderIndex] = WelderStateMoving;
        welderStepper->setSpeed(welderSpeed);
        Serial.println("WELDER STATED MOVING" + String(welderStepper->currentPosition()));
    }
  }

  if (welderState[welderIndex] == WelderStateMoving) {
    if (welderPressed) {
      welderState[welderIndex] = WelderStateWaitingSpotWeld;
      weldWaitStartTimeDelay[welderIndex] = millis();
      welderStepper->setSpeed(0);
      stepsWhenWelderStopped[welderIndex] = welderStepper->currentPosition();
      Serial.println("WELDER STOPPED MOVING" + String(welderStepper->currentPosition()));
    }
  }
  if (welderState[welderIndex] == WelderStateWaitingSpotWeld && welderTriggerState == WelderTriggerStateDone) {
//    if (millis() - weldWaitStartTimeDelay[welderIndex] > weldDelay) {
      welderState[welderIndex] = WelderStateBackingBack;
      welderStepper->setSpeed(-welderSpeed);
      Serial.println("WELDER START BACKING BACK" + String(welderStepper->currentPosition()));
//    }
  }
  if (welderState[welderIndex] == WelderStateBackingBack) {
    if ((welderStepper->currentPosition() < stepsWhenWelderStopped[welderIndex] - stepsToWelderStepBack)) {
      welderStepper->setSpeed(0);
      welderState[welderIndex] = WelderStateWaiting;
      welderTriggerState = WelderTriggerStateWaiting;
      if (welderIndex == 0) {
        welderState[1] = WelderStateReady;
      }
      Serial.println("WELDER STOPPED BACKING BACK" + String(welderStepper->currentPosition()));
    }
  }  
}



void makeBeep() {
    int delay = 140;
    for (int i = 0; i < 600; i ++) {
      digitalWrite(stripStepPin, HIGH);
      delayMicroseconds(delay); // Pulse width
      digitalWrite(stripStepPin, LOW);
      delayMicroseconds(delay); // Pulse width
    }
}
